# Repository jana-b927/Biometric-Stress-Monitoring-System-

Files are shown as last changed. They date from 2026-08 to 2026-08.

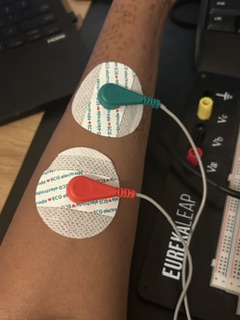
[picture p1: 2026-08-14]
testing/images/emg_placement.jpg

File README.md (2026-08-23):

# Biometric Stress Monitoring System
Multi-sensor embedded system using sensors on skin response, heart rate, and muscle tension to monitor, estimate, and display physiological arousal associated with stress. The project utilizes a photoplethysmography sensor (estimates blood volume associated with a heartbeat), galvanic skin response (measures human resistance through skin sweat conductivity), an electromyography sensor (measures muscle electrical activity) and an Arduino microcontroller to process and estimate stress from all three sensors. Metrics contributing to the estimated results are shown in a visual Python display and final results are represented physically through simple LED lights (green for relaxed, yellow for alert, and red for stressed).

# Hardware Materials and Budget: 
- Arduino UNO R4 Minima $20
- HiLetgo 5pcs 5V Heartbeat Detect PPG Sensor $7
- Grove Seeed Studio GSR Sensor $12
- EMG Muscle Signal ShillehTek Sensor $20
- 40pcs 20 cm Female to Male Wires $4 

Total budget: ~ $55

Other materials: 
- 3 led lights (220 resistor for each)
- Male to male wires
- Breadboard
- USB cord 

# General algorithm pipeline:
- Initialize everything
- Read sensor
- Filter signal
- Extract necessary features from signal
- Classify and send to LED
- If using python display print metrics to be parsed and displayed otherwise print and plot on Arduino

# Signal processing for each sensor:
**PPG:** general smoothing (moving mean), peak detection, bpm calculation, fixed thresholds 

This sensor measures the volume of blood in the finger at a given moment and when the signal peaks and records a higher volume of blood we can estimate a heartbeat. After smoothing the signal using a moving mean, peaks are detected and validated by ensuring their amplitudes are large enough and the distance between peaks is possible. After finding these peaks, the distance between peaks is found to convert to BPM. Averaging a window of BPM history smooths out the BPM signal to classify into rested or stressed lights. 

**GSR:** general smoothing (moving mean), find baseline continuously, find dips, mark threshold as a percentage 

This sensor measures human skin resistance so when its signal dips, the finger is sweatier, conducting electricity easier and leading to less resistance. The GSR sensor has 2 important parts to it, the tonic and phasic parts: the tonic part is the slow baseline drift that occurs in the signal because the person's baseline may change slowly over time, and the phasic part which are the more rapid "dips" in the signal which imply an emotionally triggering or stressful event which the body is responding to. Because of these unique features, an adaptive baseline was necessary in the GSR algorithm in order to consistently keep up with any drifting baseline. That is why after generally smoothing the signal with a simple moving mean, the algorithm takes into account deviations from the previous baseline continuously, updating it by incorporating a fraction of the current signal into the baseline. After calculating the adaptive baseline, any dips are calculated and compared to different fractions of the baseline to categorize the dip as green, yellow, or red (different arbitrary levels of stress according to threshold fractions experimented with during testing). Also, in the case where the algorithm detects a significant level of stress, the LED (yellow or red) is programmed to hold for a few seconds to display the event more clearly. 

**EMG:** RMS method, find baseline, offset, square, mean, square root, mark threshold as a percentage 

This sensor measures the amount of muscle tension in a given muscle using three electrodes: one as a reference and the other two on the belly and end of a muscle. Similar to the GSR sensor, the EMG sensor needed an adaptive baseline, because everyone has a different starting baseline for their body and using fixed values would not transfer well. For the EMG sensor, different compared to the others was the need for the RMS method in filtering and smoothing the signal. This is because the signal is special in that it oscillates around a baseline and the amplitude of that oscillation is how much more muscle tension is occurring meaning it is necessary to first find the general baseline of the signal, remove the offset, square everything to make it positive, apply the moving mean average, then square root. After this the muscle activation can be easily calculated, and the classification of stress is similar to the GSR sensor as being different threshold fractions applied to the difference in the activation compared to their adjusted baseline. 

Integrated Sensors: The integrated sensor algorithm works the same way as the others through the general algorithm pipeline described above. However, the classification of the LEDs includes a weighted stress decision where a stress score is calculated based on 2 factors: the "weight" of each sensor and the current state of each sensor. If at any point the GSR sensor is classified as red, the overall stress state is overridden to red. Else, the weighted calculation takes place. The weight each sensor has is in priority of GSR, PPG, and then EMG. This is because the GSR is more directly associated with sympathetic nervous system activation whereas a heartbeat can be influenced not only by stress but also by events such as exercise or caffeine, and the EMG sensor can be triggered directly through voluntary motion. 

Python Display: The Python display was built to more clearly and easily visualize a chaotic amount of data. The algorithm first parses the data given by the Arduino and plots a graph for each sensor to visualize important information and a final report: the raw and smoothed signals as well as any other calculated features and final metrics such as the baselines, BPM, amplitudes, and overall stress score/ state. 

# Future Improvements: 
--> actively working on 
- working on a custom pcb to replace temporary breadboard and actually wearable

--> others to consider
- wireless communication instead of arduino connected to laptop - app to visually display stress less technically (not through graphs) 
- change emg sensor placement and different integration of sensors to be more stress accurate instead of general estimation
- better quality and resolution hardware
- more advanced software filtering
- extract more features from each signal to take into account
- implement more specific and experimented on/ researched thresholds instead of relying one singular individual's testing
- use machine learning to extract features instead of fixed thresholds

# Applications: 
- personal and medical stress management through live feedback and awareness
- nonverbal individual ability to express simple visual stress levels - inexpensive and accessible
- research on biometric stress estimation
- research on individual stress management

# Limitations: 
- technically stress estimation of physiological arousal instead of direct stress measurement because of many different factors potentially affecting results - excessive movement, exercise, caffeine, excitement etc. 
- sensor accuracy (cheaply and simply made)
- movement makes signals very noisy and placement of sensors on the body also affects results
- limited memory
- estimated thresholds based on personal testing - could need adjustment for different people

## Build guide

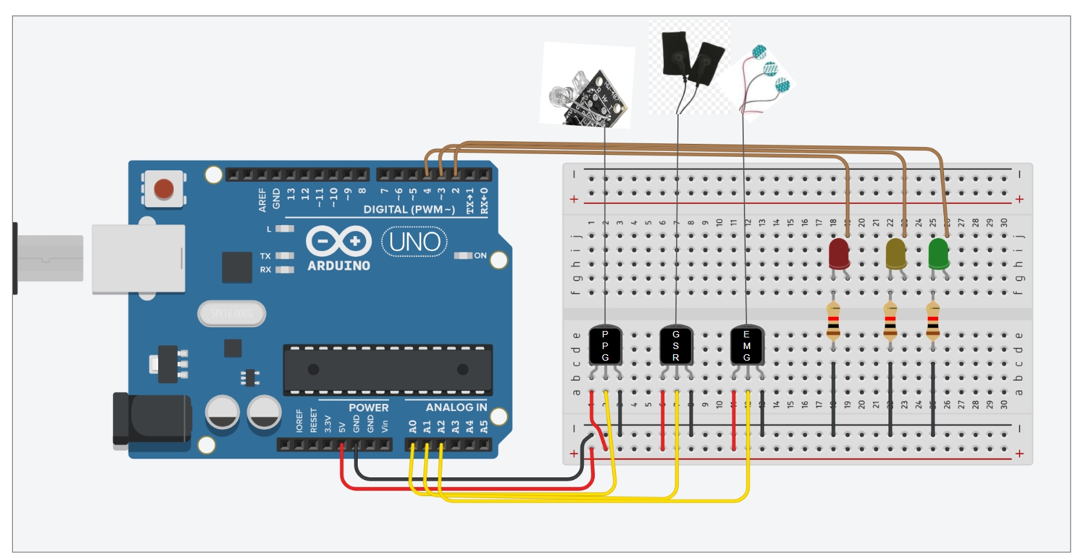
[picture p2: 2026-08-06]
hardware/tinkercad/final wiring.jpeg

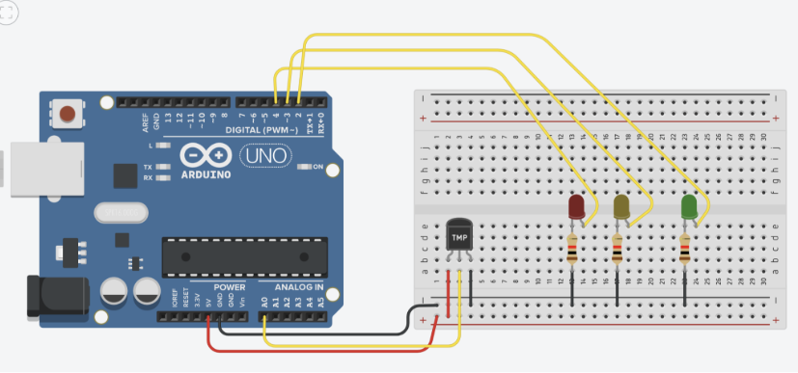
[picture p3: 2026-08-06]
hardware/tinkercad/wiring of one sensor.png

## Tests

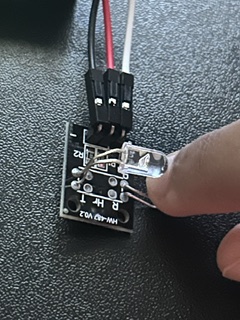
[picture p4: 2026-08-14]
testing/images/ppg_placement.jpg

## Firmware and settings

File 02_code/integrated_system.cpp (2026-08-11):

//integrated stress detection: PPG + GSR + EMG -> single 3-LED readout

//---- pins ----
const int ppgPin = A1;
const int gsrPin = A2;
const int emgPin = A0;

const int greenLED = 2;
const int yellowLED = 3;
const int redLED = 4;

//========== initialize PPG (heartbeat) ==========
const int ppgWindowSize = 10;  //potentially subject to change * comment
int ppgSamples[ppgWindowSize];
int ppgSampleIndex = 0;
long ppgSampleSum = 0;

float ppgPrev = 0;
float ppgCurr = 0;
float ppgNext = 0;

unsigned long prevPeak = 0;
float bpm = 0;
const int bpmWindow = 5; 
float bpmHistory[bpmWindow];
int bpmIndex = 0;
float bpmSum = 0;
float averageBPM = 0;

const int minPeakDist = 300;
const float minPeakDifference = .05;

const float ppgMaxRest = 90;
const float ppgElev = 120;

int ppgState = 0; //0=green,1=yellow,2=red

//========== initialize GSR ==========
const int gsrWindowSize = 5; //potentially subject to change * comment
int gsrSamples[gsrWindowSize];
int gsrSampleIndex = 0;
long gsrSampleSum = 0;

float gsrBaseline = 0;
const float gsrBaselineAlpha = 0.01; 

const float threshold1_gsr = 0.05; //potentially subject to change * comment
const float threshold2_gsr = 0.1; //potentially subject to change * comment

unsigned long redTime = -10000;
unsigned long yellowTime = -10000;

//========== initialize EMG ==========
const int emgWindowSize = 20; //potentially subject to change * comment
float emgSquaredSamples[emgWindowSize];
int emgSampleIndex = 0;
float emgSquaredSum = 0;

float drift = 0;
const float driftAlpha = 0.01;

float rmsBaseline = 0;

float baselineSum_emg = 0;
int baselineSamples_emg = 0;
const unsigned long baselineTime_emg = 2000;

const float threshold1_emg = 0.3; //potentially subject to change * comment
const float threshold2_emg = 0.6; //potentially subject to change * comment

//========== Sensor Weights ==========
const float gsrWeight = 0.40; //potentially subject to change * comment
const float ppgWeight = 0.35; //potentially subject to change * comment
const float emgWeight = 0.25; //potentially subject to change * comment
float threshold1_overall = .5;
float threshold2_overall = 1.25;
float threshold3_overall = 2;

void setup()
{
    Serial.begin(9600);

    pinMode(greenLED, OUTPUT);
    pinMode(yellowLED, OUTPUT);
    pinMode(redLED, OUTPUT);

    for (int i = 0; i < ppgWindowSize; i++) { ppgSamples[i] = 0; }
    for (int i = 0; i < gsrWindowSize; i++) { gsrSamples[i] = 0; }
    for (int i = 0; i < emgWindowSize; i++) { emgSquaredSamples[i] = 0; }
    for (int i = 0; i < bpmWindow; i++) { bpmHistory[i] = 0; }
}

void loop()
{
    unsigned long now = millis();

    //----Read Sensors ----
    int rawPPG = analogRead(ppgPin);
    int rawGSR = analogRead(gsrPin);
    int rawEMG = analogRead(emgPin);

    //---- Filter Signals ----

    //PPG moving mean
    ppgSampleSum -= ppgSamples[ppgSampleIndex];
    ppgSamples[ppgSampleIndex] = rawPPG;
    ppgSampleSum += ppgSamples[ppgSampleIndex];
    ppgSampleIndex++;
    if (ppgSampleIndex >= ppgWindowSize) {ppgSampleIndex = 0; }
    float ppgSmooth = (float)ppgSampleSum / ppgWindowSize;

    ppgPrev = ppgCurr;
    ppgCurr = ppgNext;
    ppgNext = ppgSmooth;

    //GSR moving mean
    gsrSampleSum -= gsrSamples[gsrSampleIndex];
    gsrSamples[gsrSampleIndex] = rawGSR;
    gsrSampleSum += gsrSamples[gsrSampleIndex];
    gsrSampleIndex++;
    if (gsrSampleIndex >= gsrWindowSize) { gsrSampleIndex = 0; }
    float gsrSmooth = (float)gsrSampleSum / gsrWindowSize;

    //EMG offset removal + RMS
    if (drift == 0) {drift = rawEMG; }
    else { drift = drift + driftAlpha * (rawEMG - drift); }

    float emgCentered = rawEMG - drift;
    float emgSquared = emgCentered * emgCentered;

    emgSquaredSum -= emgSquaredSamples[emgSampleIndex];
    emgSquaredSamples[emgSampleIndex] = emgSquared;
    emgSquaredSum += emgSquaredSamples[emgSampleIndex];
    emgSampleIndex++;
    if (emgSampleIndex >= emgWindowSize) { emgSampleIndex = 0; }
    float emgRMS = sqrt(emgSquaredSum / emgWindowSize);

    //---- Extract Features ----

    //GSR baseline + dip amplitude
    if (gsrBaseline == 0) { gsrBaseline = gsrSmooth; }
    else { gsrBaseline = gsrBaseline + gsrBaselineAlpha * (gsrSmooth - gsrBaseline); }

    float dipAmplitude = gsrBaseline - gsrSmooth;
    if (dipAmplitude < 0) { dipAmplitude = 0; }

    //EMG RMS baseline calibration (first 2 seconds), then fixed baseline
    if (now < baselineTime_emg)
    {
        baselineSum_emg += emgRMS;
        baselineSamples_emg++;
    }
    else if (rmsBaseline == 0)
    {
        rmsBaseline = baselineSum_emg / baselineSamples_emg;
    }

    float activation = emgRMS - rmsBaseline;
    if (activation < 0) {activation = 0;}

    //PPG peak detection + BPM (updates ppgState when a peak completes)
    if (ppgCurr > ppgPrev && ppgCurr > ppgNext &&
        ppgCurr - ppgPrev > minPeakDifference && ppgCurr - ppgNext > minPeakDifference)
    {
        if (now - prevPeak > minPeakDist)
        {
            if (prevPeak != 0)
            {
                unsigned long intv = now - prevPeak;
                bpm = 60000.0 / intv;
                bpmSum -= bpmHistory[bpmIndex];
                bpmHistory[bpmIndex] = bpm;
                bpmSum += bpmHistory[bpmIndex];
                bpmIndex++;
                if (bpmIndex >= bpmWindow) bpmIndex = 0;
                averageBPM = bpmSum / bpmWindow;
            }

            prevPeak = now;

            //---- Classify PPG ----
            if (averageBPM > 0)
            {
                if (averageBPM < ppgMaxRest) ppgState = 0;
                else if (averageBPM < ppgElev) ppgState = 1;
                else ppgState = 2;
            }
        }
    }

    //---- Classify GSR ----
    if (dipAmplitude >= threshold2_gsr * gsrBaseline)
    {
        redTime = now;
    }
    else if (dipAmplitude >= threshold1_gsr * gsrBaseline)
    {
        yellowTime = now;
    }

    //---- GSR Hold Logic ----
    int gsrState;
    if (now - redTime < 3000) gsrState = 2;
    else if (now - yellowTime < 2000) gsrState = 1;
    else gsrState = 0;

    //---- Classify EMG ----
    int emgState;
    if (activation < threshold1_emg * rmsBaseline) emgState = 0;
    else if (activation < threshold2_emg * rmsBaseline) emgState = 1;
    else emgState = 2;

  //---- Weighted Stress Decision ----

    // Calculate weighted stress score
    float stressScore =
    (gsrWeight * gsrState) +
    (ppgWeight * ppgState) +
    (emgWeight * emgState);

    // Convert weighted score into LED state
    int overallState;
    //override overall state if gsr picks up red  //potentially subject to change * comment
    if (gsrState == 2){
        overallState = 2;
    }
    else
{
    
    if (stressScore < threshold1_overall){overallState = 0;}      // Green}
    else if (stressScore < threshold2_overall) {overallState = 1;}      // Yellow}
    else{overallState = threshold3_overall; }     // Red
}
    //---- 7. Update LEDs ----
    digitalWrite(greenLED, LOW);
    digitalWrite(yellowLED, LOW);
    digitalWrite(redLED, LOW);

    if (overallState == 0) {digitalWrite(greenLED, HIGH);}
    else if (overallState == 1) {digitalWrite(yellowLED, HIGH);}
    else {digitalWrite(redLED, HIGH);}

    //---- Send Metrics via Serial ----
    Serial.print(rawPPG);
Serial.print(",");
Serial.print(ppgSmooth);
Serial.print(",");
Serial.print(averageBPM);
Serial.print(",");
Serial.print(ppgState);

Serial.print(",");

Serial.print(rawGSR);
Serial.print(",");
Serial.print(gsrSmooth);
Serial.print(",");
Serial.print(gsrBaseline);
Serial.print(",");
Serial.print(dipAmplitude);
Serial.print(",");
Serial.print(gsrState);

Serial.print(",");

Serial.print(rawEMG);
Serial.print(",");
Serial.print(emgRMS);
Serial.print(",");
Serial.print(activation);
Serial.print(",");
Serial.print(emgState);

Serial.print(",");

Serial.print(stressScore);
Serial.print(",");
Serial.println(overallState);

    delay(10);
}

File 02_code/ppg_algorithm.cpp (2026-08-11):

//heartbeat sensor algorithm
 
//wiring setup for pins and leds 
const int ppgPin = A1;
const int greenLED = 2;
const int yellowLED = 3;
const int redLED = 4;

//smoothing setup (moving mean)
const int windowSize = 10;
int samples[windowSize];
int sampleIndex = 0;
long sampleSum = 0;

float prev = 0;
float curr = 0;
float next = 0;

//bpm setup
unsigned long prevPeak = 0;
float bpm = 0;
const int bpmWindow = 5;
float bpmHistory[bpmWindow];
int bpmIndex = 0;
float bpmSum = 0;
float averageBPM = 0;

//adaptive threshold setup
const int minPeakDist = 300; 
const float minPeakDifference = .05;

//fixed thresholds on known resting or elevated bpms
const int max_rest = 90;
const int elev = 120; 

void setup()
{
    Serial.begin(9600);

    pinMode(greenLED, OUTPUT);
    pinMode(yellowLED, OUTPUT);
    pinMode(redLED, OUTPUT);

    //initialize moving average
    for(int i = 0; i < windowSize; i++)
    {
        samples[i] = 0;
    }

    //initialize BPM history
    for(int i = 0; i < bpmWindow; i++)
    {
        bpmHistory[i] = 0;
    }
}

void loop()
{
    int raw = analogRead(ppgPin);

    //moving mean to smooth general signal
    sampleSum -= samples[sampleIndex];
    samples[sampleIndex] = raw;
    sampleSum += samples[sampleIndex];
    sampleIndex++;

    if(sampleIndex >= windowSize)
        sampleIndex = 0;

    float smoothValue = (float)sampleSum / windowSize;

    //shift values
    prev = curr;
    curr = next;
    next = smoothValue;

    //detect peaks
    if((curr > prev ) && (curr > next ) && (curr - prev > minPeakDifference ) && (curr - next > minPeakDifference))
    {
        unsigned long currTime = millis();
    //make sure peaks are far enough apart
        if(currTime - prevPeak > minPeakDist)
        {
            // calculate BPM after first peak
            if(prevPeak != 0)
            {
                unsigned long intv = currTime - prevPeak;

                bpm = 60000.0 / intv;

                // moving average of BPM
                bpmSum -= bpmHistory[bpmIndex];
                bpmHistory[bpmIndex] = bpm;
                bpmSum += bpmHistory[bpmIndex];
                bpmIndex++;

                if(bpmIndex >= bpmWindow)
                    bpmIndex = 0;

                averageBPM = bpmSum / bpmWindow;
            }

            // save current peak time
            prevPeak = currTime;
        }
    }

    // LED thresholds
    digitalWrite(greenLED, LOW);
    digitalWrite(yellowLED, LOW);
    digitalWrite(redLED, LOW);

    if(averageBPM > 0)
    {
        if(averageBPM < max_rest)
        {
            digitalWrite(greenLED, HIGH);
        }
        else if(averageBPM < elev)
        {
            digitalWrite(yellowLED, HIGH);
        }
        else
        {
            digitalWrite(redLED, HIGH);
        }
    }


    //plot and print 
    Serial.print("Raw:");
    Serial.print(raw);

    Serial.print(",");

    Serial.print("Smoothed:");
    Serial.print(smoothValue);

    
    Serial.print(",");

    Serial.print("bpm:");
    Serial.println(averageBPM);
    



    delay(10);
}

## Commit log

2026-08-10 debug ppg sensor
2026-08-10 adjusted emg algorithm to remove adpatible baseline and calibrate at the beginning
2026-08-23 update organization
    [wiring schematic.kicad_sch]
